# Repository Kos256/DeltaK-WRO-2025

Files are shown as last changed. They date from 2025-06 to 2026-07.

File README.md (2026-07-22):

<center><h1> Delta K - WRO 2025 Future Engineers </h1></center>

<!-- ⚠️⚠️⚠️ REMINDER: ADD TEAM BANNER IMAGE HERE ⚠️⚠️⚠️ -->
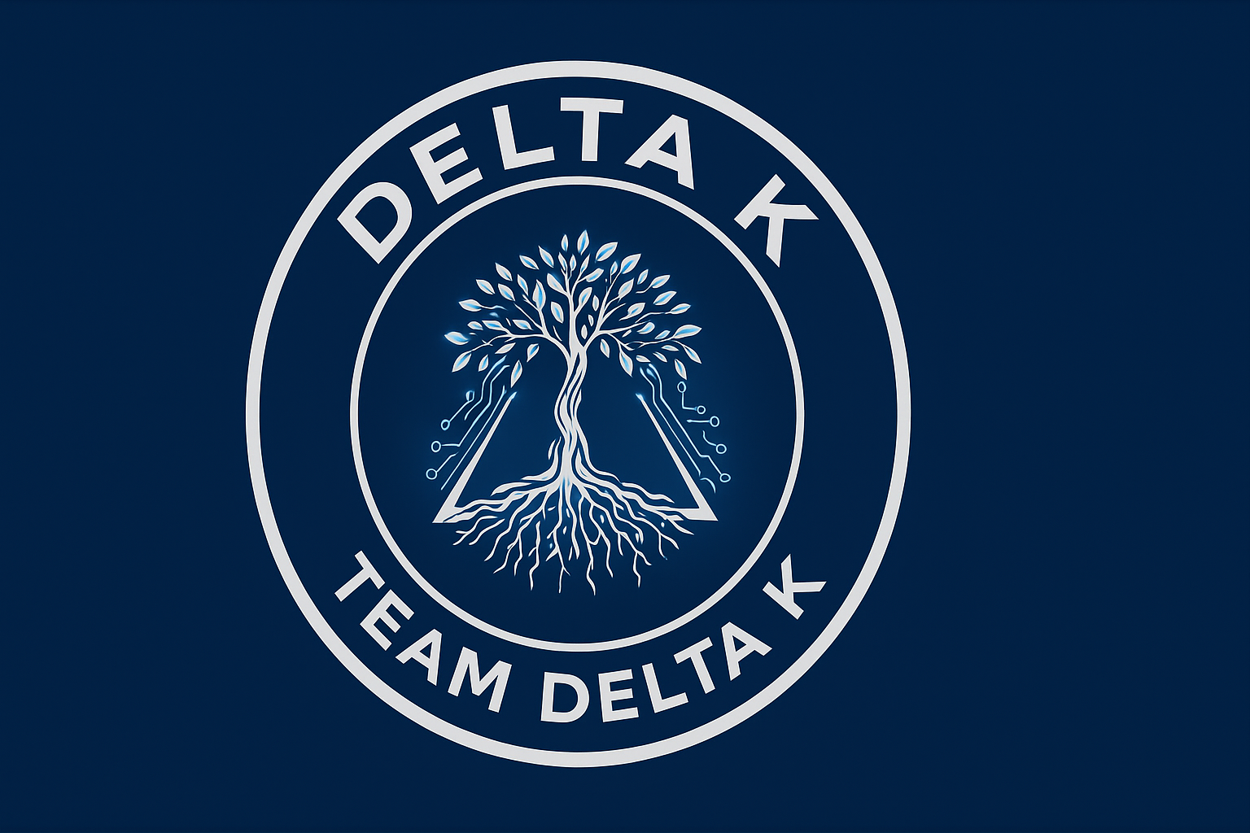
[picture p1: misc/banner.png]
Banner




This repository contains the complete documentation for Team Delta K's autonomous robot for the 2025 World Robot Olympiad Future Engineers competition. Delta Bot was designed, built, and programmed by three dedicated students from Karachi, Pakistan, representing Haque Academy on the international stage.

## Table of Contents
* [The Team](#team)
* [The Challenge](#challenge)
* [The Robot](#robot-image)
* [Performance Video](#video)
* [Development Journey](#development-journey)
* [Mobility Management](#mobility-management)
  * [Custom Motor Design](#custom-motor-design)
  * [Steering System](#steering-system)
  * [Drivetrain](#drivetrain)
  * [Chassis](#chassis)
  * [Wheels](#wheels)
* [Power and Sense Management](#power-and-sense-management)
  * [Raspberry Pi 5](#raspberry-pi-5)
  * [XRP Controller Board](#xrp-board)
  * [Vision System - PiCam2](#picam2)
  * [RPLidar A2M12](#rplidar)
  * [LSM6DSOX IMU](#imu-sensor)
  * [HC-SR04 Ultrasonic Sensor](#ultrasonic)
  * [Motor Encoder](#motor-encoder)
  * [Power System](#power-system)
  * [Circuit Diagram](#circuit-diagram)
* [Software Architecture](#software-architecture)
  * [Code Structure](#code-structure)
  * [Computer Vision](#computer-vision)
  * [Sensor Fusion](#sensor-fusion)
  * [Communication Protocol](#communication)
* [Obstacle Management](#obstacle-management)
  * [Qualification Round Strategy](#quali-strategy)
  * [Obstacle Round Strategy](#obstacle-strategy)
  * [Parking Challenge](#parking-challenge)
* [Code Implementation](#code-implementation)
  * [Main Control Loop](#main-loop)
  * [LiDAR Mapping](#lidar-code)
  * [Color Detection](#color-detection-code)
  * [IMU Integration](#imu-code)
  * [Motor Control](#motor-control-code)
  * [Obstacle Avoidance](#obstacle-avoidance-code)
* [Robot Construction Guide](#robot-construction-guide)
* [Cost Report](#cost-report)
* [Testing & Results](#testing-results)
* [Future Improvements](#future-improvements)
* [Acknowledgments](#acknowledgments)
* [Resources](#resources)
* [License](#license)

---

## The Team 

<!-- ⚠️⚠️⚠️ REMINDER: ADD ALL TEAM MEMBER PHOTOS IN ./team-photos/ FOLDER ⚠️⚠️⚠️ -->

### Kabir - Project Manager & Documentation Lead
<p align="center">
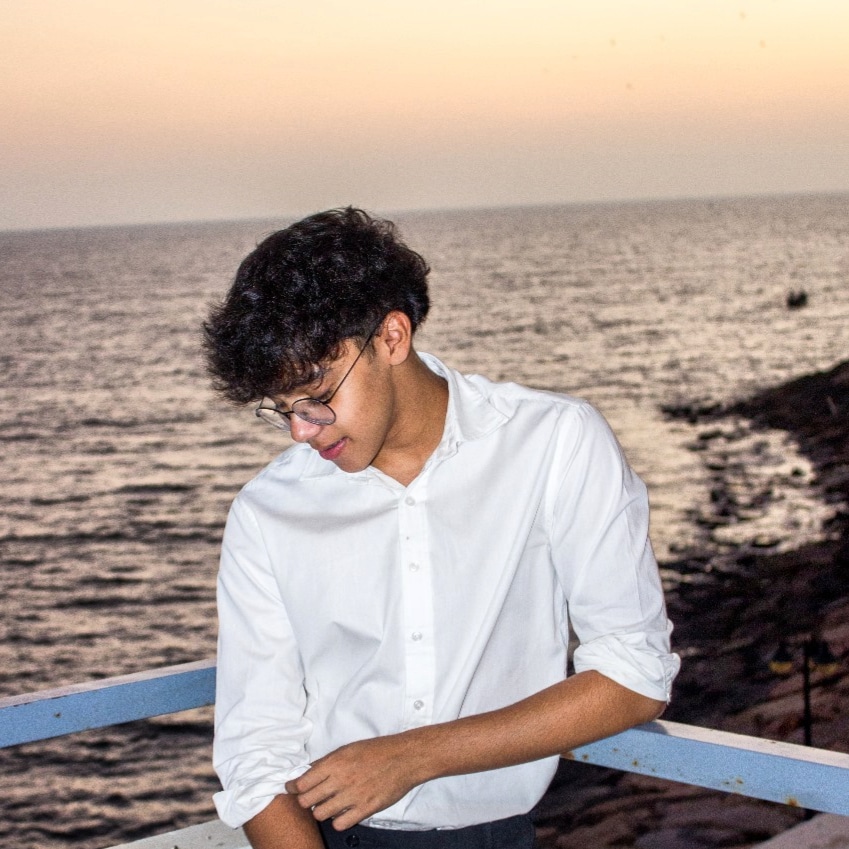
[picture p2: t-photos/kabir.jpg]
Kabir
  
</p>

**Age:** 15

**School:** Haque Academy, Karachi, Pakistan

**Role:** Project Manager & Documentation Lead

**Description:** Hi! I'm Kabir, and I'm passionate about programming, public speaking, leadership, and staying fit through gymming. WRO 2025 represents an incredibly interesting challenge and a golden opportunity to showcase our robotics skills on the international stage. My strengths lie in organizing the team, maintaining comprehensive documentation, managing our GitHub repository, and planning the robot's development roadmap. I previously qualified at the national level for the International Robot Olympiad (IRO) in Greece, which gave me valuable competition experience. What I enjoy most about my role is seeing our robot's progress grow in real-time—watching our ideas transform from sketches to a fully functional autonomous vehicle is incredibly rewarding. Leading this team and documenting every step of our journey has taught me that success comes from meticulous planning, clear communication, and relentless dedication to improvement.

---

### Kosain - Lead Programmer
<p align="center">
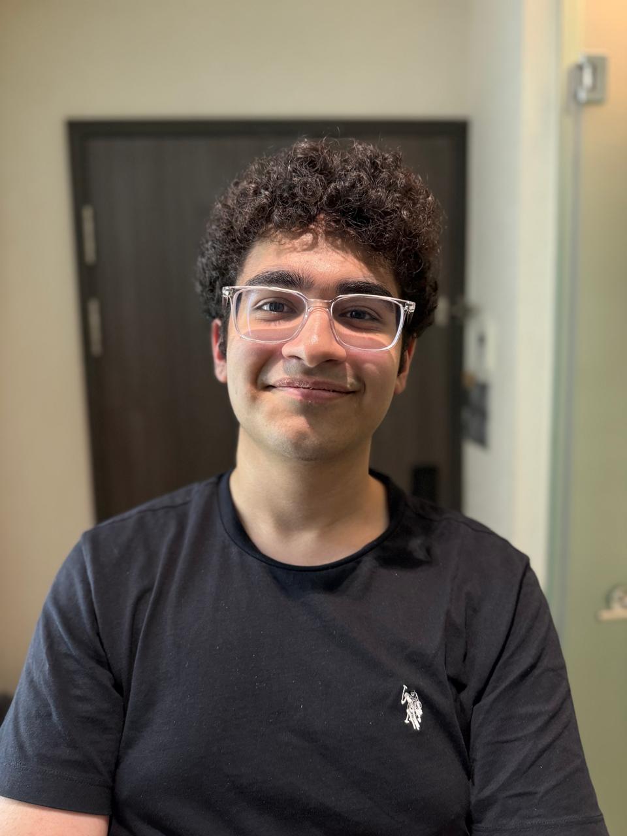
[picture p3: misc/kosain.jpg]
Kosain
  
</p>

**Age:** 16

**School:** Haque Academy, Karachi, Pakistan

**Role:** Lead Programmer

**Description:** Hello! I'm Kosain, the lead programmer for Team Delta K. I've been fascinated by programming since I was 6 or 7 years old—what drew me in was how extremely logical it is, and my school provided many opportunities to learn and grow. Over the years, I've become proficient in Python, C, C++, C#, HTML, CSS, and JavaScript. I've worked on diverse projects including wireless remote control protocols, AI frontend development, image editor software built on ESP32, an electronic dice, a formula calculator, and even a malware debunker tool. What I love most about programming is its pure logic—every problem has a solution if you think systematically. Beyond software, I have a strong interest in the hardware side of things, which is why robotics is the perfect blend of my passions. For this competition, I'm handling all the computer vision, sensor integration, and control algorithms that bring Delta Bot to life. The challenge of making real-time decisions based on multiple sensor inputs is exactly the kind of complex problem I thrive on solving.

---

### Rayyan - Lead Hardware & Construction
<p align="center">
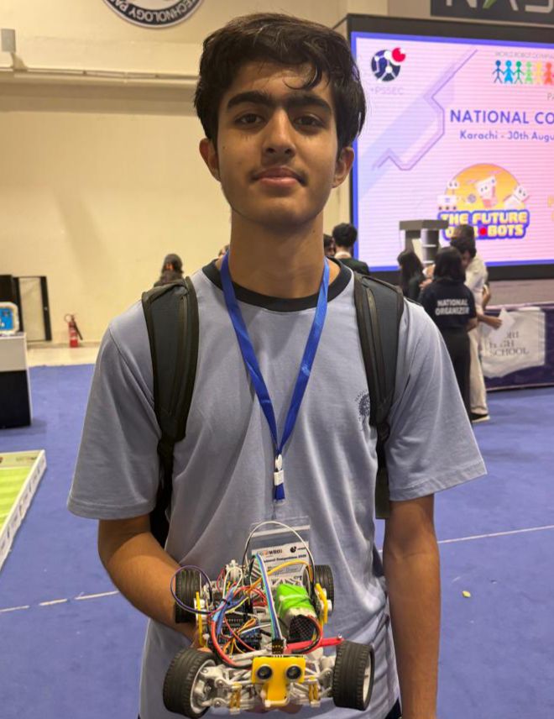
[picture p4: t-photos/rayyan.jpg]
Rayyan
  
</p>

**Age:** 15

**School:** Haque Academy, Karachi, Pakistan

**Role:** Lead Hardware & Construction

**Description:** Hi ! I’m Rayyan, I have been passionate about robotics, engineering, and hands-on building for as long as I can remember. My STEM journey began with the First LEGO League Junior National Competition in 2019, and since then I’ve developed strong skills in 3D printing, CAD design, and mechanical construction. I’m especially fascinated by gears, linkages, and structural integrity, and I love modifying and customizing RC cars into high-speed performance builds.
As the Lead Hardware & Construction member of Team Delta K, I designed, assembled, and 3D-printed our autonomous robot for the WRO Future Engineers category. My interest in fabrication also inspired me to co-found @rk3dprints, where my teammate and I create innovative 3D-printed products.
Outside robotics, I enjoy fishing, building natural habitat aquariums, rowing as Captain of my school’s team, and exploring culinary arts. I’m excited to gain international exposure at WRO 2025 and take my passion for innovation to the global stage.

---

### Ali Saif - Coach
<p align="center">
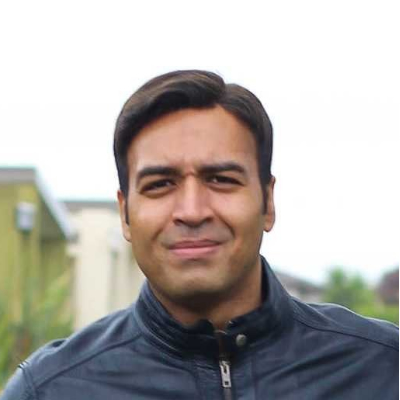
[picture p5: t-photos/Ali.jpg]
Ali Saif
  
</p>

**Role:** Team Coach

**Description:** Leveraging a robust engineering background, Ali Saif is an entrepreneur dedicated to solving challenging market problems through innovation. He combine technical rigor with business acumen to build and grow companies that are disrupting the technology landscape.

---

### Team Photo
<p align="center">
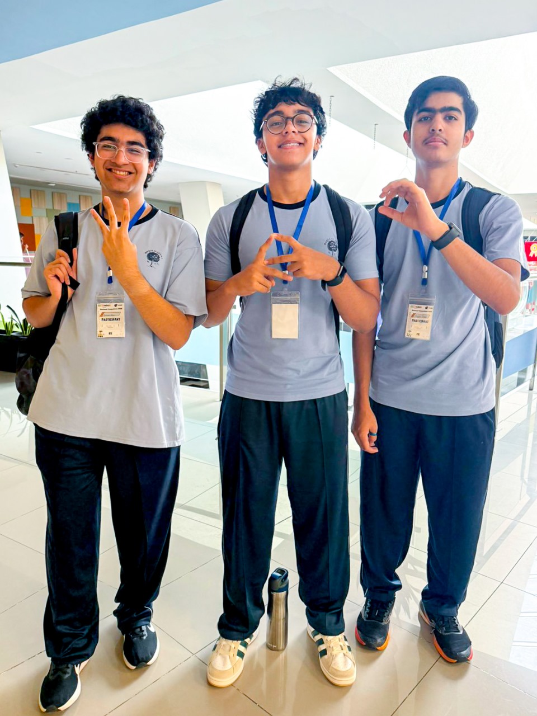
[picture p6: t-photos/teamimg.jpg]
Team Delta K
  
</p>

<!-- ⚠️⚠️⚠️ REMINDER: ADD TEAM FORMATION STORY & DYNAMICS ⚠️⚠️⚠️ -->
<!-- Include: How the team formed, how you knew each other, why you decided to work together, team dynamic, how you divide work, resolve disagreements, memorable moments during development -->

**Team Formation:** [Describe how Delta K was formed, how team members knew each other beforehand, what brought you together for WRO, and what makes your team dynamic special]

**Team Dynamic:** [Explain how you work together, divide responsibilities, handle disagreements, celebrate successes, and any funny or memorable moments during the 6-month development process]

---

## The Challenge 

The **[WRO 2025 Future Engineers - Self-Driving Cars](https://wro-association.org/)** challenge represents the pinnacle of student robotics competitions, inviting teams worldwide to design, build, and program fully autonomous vehicles. The competition simulates real-world self-driving car scenarios with three distinct challenges:

**1. Open Challenge (Qualification Round):** Robots must autonomously navigate a track with randomly placed walls, completing three laps in the fastest time possible. The direction of travel (clockwise or counterclockwise) is determined by detecting colored lines (orange or blue) at the track's corners.

**2. Obstacle Challenge (Final Round):** Building on the qualification round, robots must now avoid randomly placed traffic signs (red and green pillars) while maintaining speed and efficiency. The challenge includes a mandatory U-turn rule: if the last obstacle in the second lap is red, the robot must turn around and complete the final lap in the opposite direction.

**3. Parking Challenge:** After completing the obstacle rounds, robots must identify a parking space marked by magenta walls and execute a precise parallel parking maneuver.

**Key Technical Requirements:**
- **Mobility Management:** Efficient motor control, precise steering, and robust mechanical design
- **Sensor Fusion:** Integration of multiple sensors (camera, LiDAR, IMU, encoders) for environmental awareness
- **Computer Vision:** Real-time color detection and object recognition for obstacles and parking spaces
- **Path Planning:** Dynamic navigation using sensor data to avoid collisions and optimize routes
- **Documentation:** Comprehensive engineering documentation in a public GitHub repository demonstrating the entire development process

**Scoring Criteria:**
- Performance in competition rounds (speed, accuracy, obstacle avoidance)
- Quality and completeness of engineering documentation
- Innovation in design and problem-solving approaches
- Team presentation and ability to explain technical decisions

This challenge emphasizes the complete engineering process—from conceptual design through iterative prototyping, testing, and final implementation. It pushes teams to integrate mechanical engineering, electronics, computer science, and project management skills while fostering creativity, teamwork, and resilience in the face of technical challenges.

Learn more about the WRO 2025 challenge rules and specifications [here](https://wro-association.org/competition/season-2025/).

---

## Photos of Our Robot: Delta Bot 

<!-- ⚠️⚠️⚠️ REMINDER: ADD ALL SIX ROBOT PHOTOS (front, back, left, right, top, bottom) IN ./robot-photos/ FOLDER ⚠️⚠️⚠️ -->

Delta Bot represents our team's sixth month of intensive engineering, combining cutting-edge sensors with custom mechanical solutions. Powered by a Raspberry Pi 5 and equipped with RPLidar for 360-degree environmental mapping, Delta Bot achieves autonomous navigation through advanced sensor fusion and real-time path planning.

| Front View | Back View | 
| :--: | :--: |
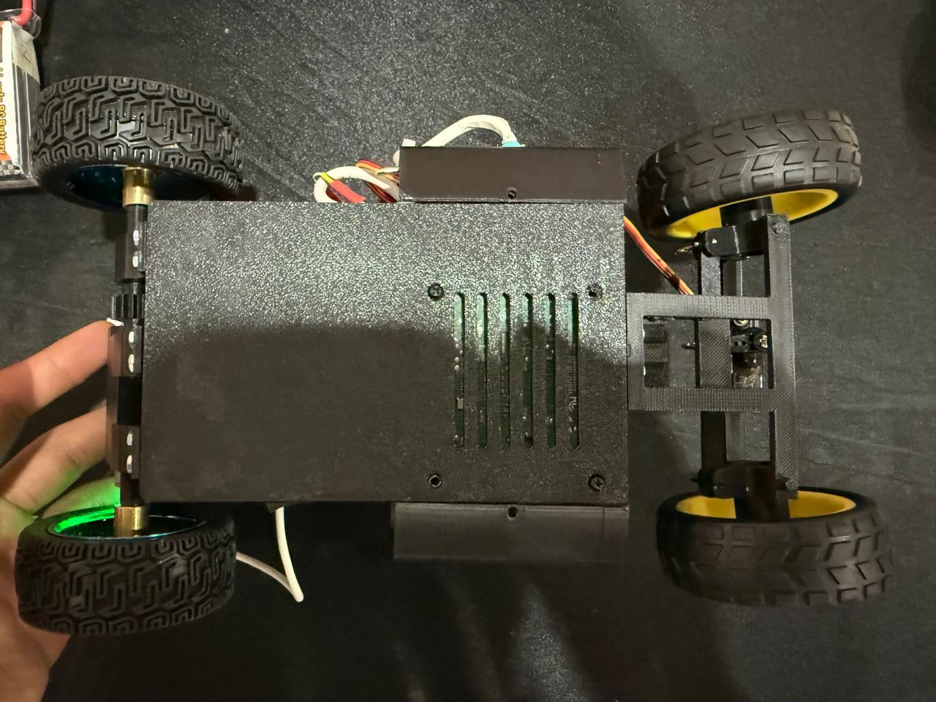
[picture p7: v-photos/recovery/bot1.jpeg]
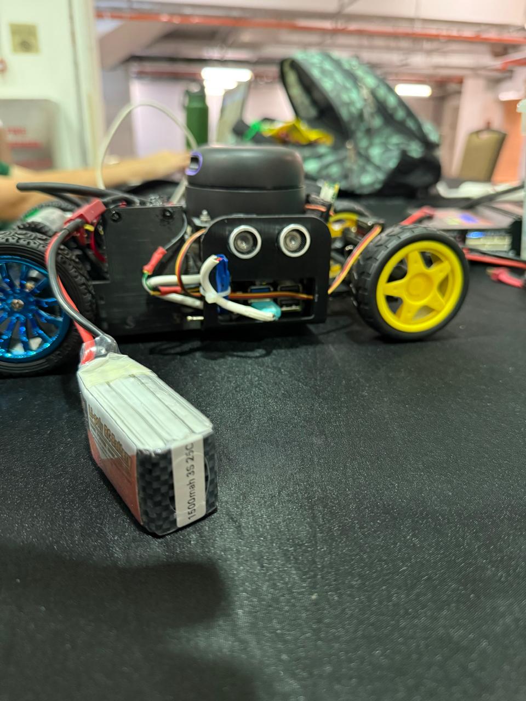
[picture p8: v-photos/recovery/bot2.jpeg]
|  |  |
| **Left View** | **Right View** |
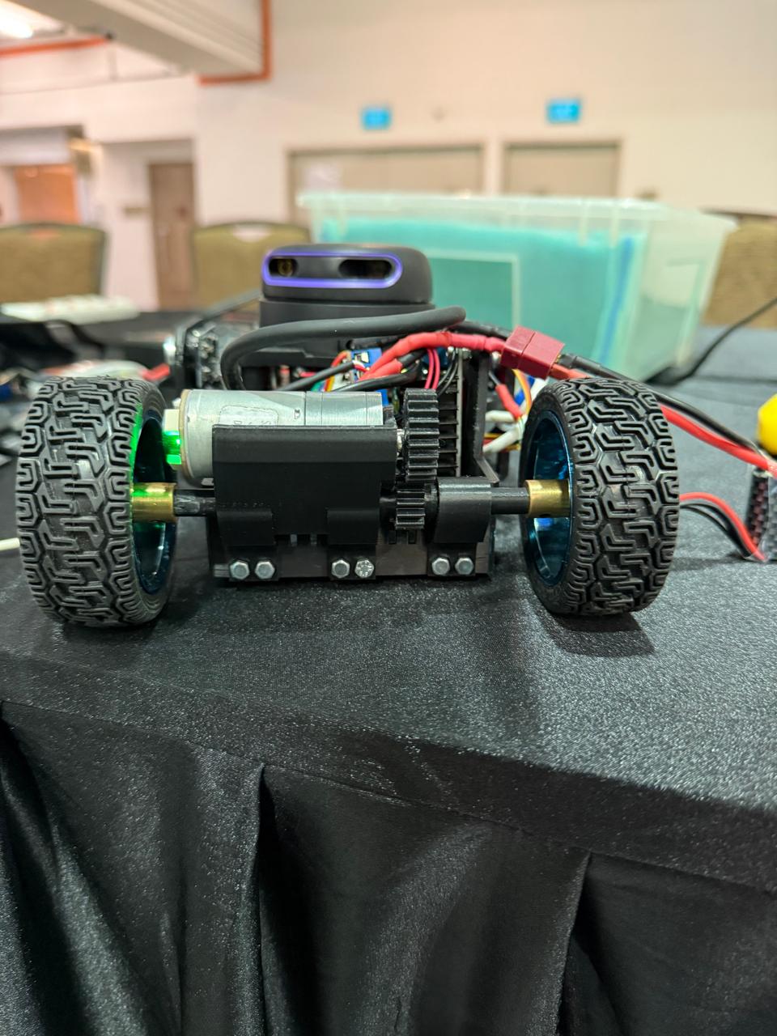
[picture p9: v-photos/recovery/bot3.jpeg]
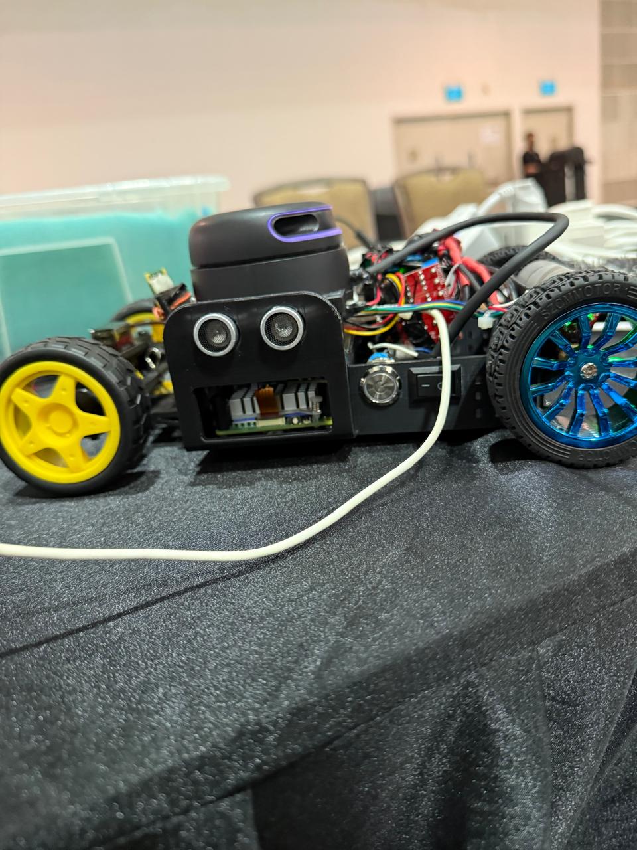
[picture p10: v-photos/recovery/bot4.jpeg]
|  |  |
| **Top View** | **Bottom View** |
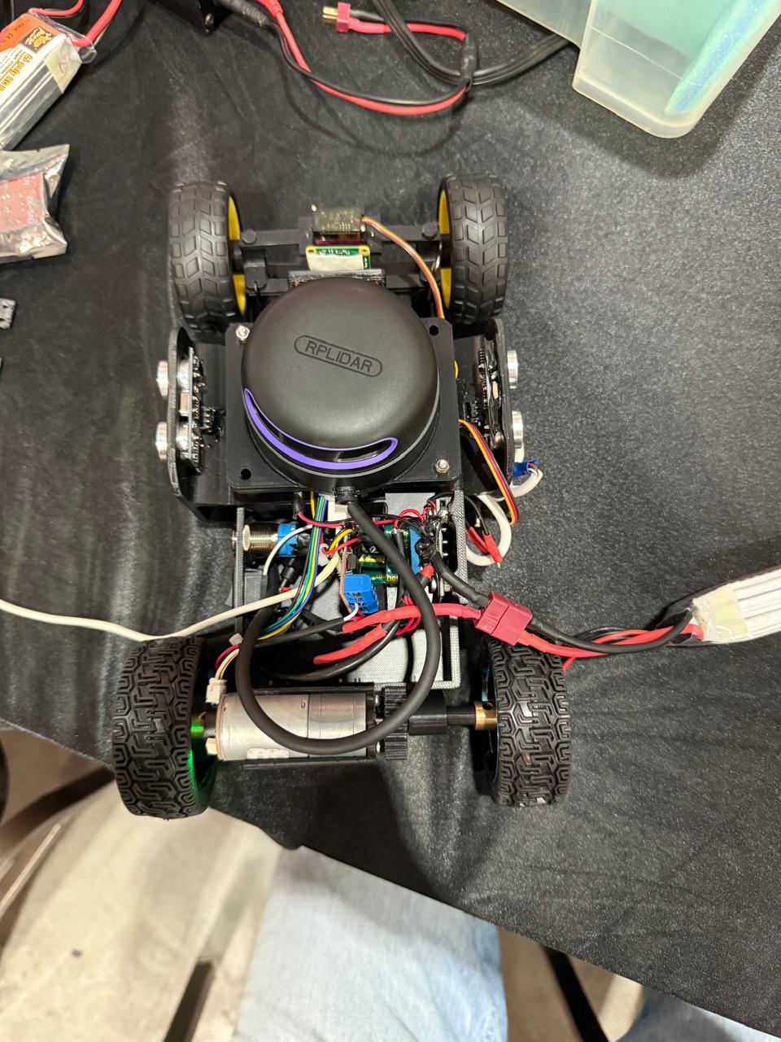
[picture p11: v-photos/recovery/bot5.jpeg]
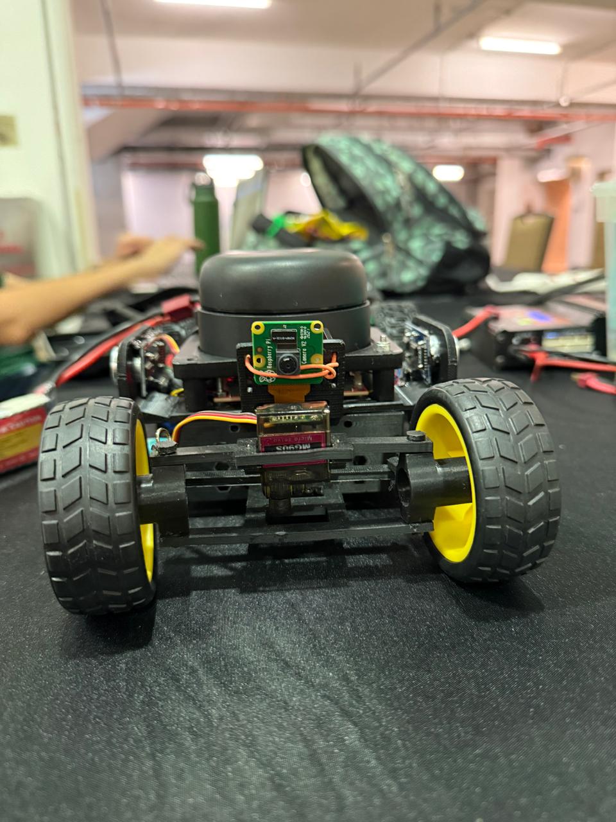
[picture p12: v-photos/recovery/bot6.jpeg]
|  |  |

**Key Specifications:**
- **Dimensions:** 270mm x 190mm x 100mm
- **Weight:** 1030g
- **Brain:** Raspberry Pi 5 (8-core CPU, 8GB RAM)
- **Vision:** PiCam2 with OpenCV processing
- **Mapping:** RPLidar A2M12 (360° scanning, 12m range)
- **Navigation:** LSM6DSOX IMU (6-axis gyroscope + accelerometer)
- **Drive System:** Custom dual-axle motor with DG01D-E encoder
- **Steering:** SG90 micro servo with parallel linkage mechanism
- **Power:** 3x 1500mAh LiPo batteries with voltage regulation
- **Construction:** 3D printed PLA+ & ABS components

---
<!-- uncomment this when performance video is uploaded
## Our Performance Video 

Watch Delta Bot in action [here](https://https://google.com)
**(link to youtube video has yet to be added)**

**Competition Performance Highlights:**
- **Qualification Round Best Time:** 14 seconds
- **Obstacle Round Score:** 10.0 (14 points)
- **National Competition Result:** 3rd Place (Qualified for International Competition)
-->
---
## Development Journey 

Delta Bot's development spanned six months and four major design iterations, each addressing critical challenges and pushing our capabilities further.

### **Iteration 1: The Arduino Attempt (Month 1)**
Our first design used an Arduino Uno as the main controller with basic ultrasonic sensors for navigation. We quickly discovered the Arduino's limitations:
- **Camera compatibility** was extremely unstable and unreliable
- **Color sensors** proved inadequate for the obstacle challenge—they couldn't reliably distinguish between red and green traffic signs
- **Processing power** was insufficient for real-time decision-making

**Lesson Learned:** Budget hardware severely limits autonomous capabilities. Vision and processing power are non-negotiable for competition-level performance.

### **Iteration 2: Raspberry Pi 4 with Ambition (Months 2-3)**
We upgraded to a Raspberry Pi 4, expecting significant improvements. Instead, we encountered our biggest setback:
- **Camera communication** took nearly a month to debug—the Pi 4 struggled with consistent PiCam integration
- **LiDAR data overload**—the RPLidar A2M12 generates massive amounts of data, completely overwhelming the Pi 4's processing capabilities
- The robot would freeze or make delayed decisions, making it completely uncompetitive

**Breakthrough Moment:** We realized we needed significantly more processing power, not just incremental upgrades.

### **Iteration 3: The Raspberry Pi 5 Revolution (Month 4)**
Switching to the Raspberry Pi 5 transformed our project:
- **8-core processor** effortlessly handled LiDAR data, camera processing, and navigation algorithms simultaneously
- **Improved camera support** eliminated communication issues entirely
- **Real-time performance** finally achieved—Delta Bot could process sensor data and react within milliseconds

This upgrade was expensive but absolutely critical to our success.

### **Iteration 4: Mechanical Refinement & Custom Motor (Months 5-6)**
With electronics stable, we focused on mechanical optimization:
- **30+ 3D printed parts:** Designed and refined chassis, motor mounts, sensor holders, and linkages
- **Weight optimization:** Iterative printing reduced unnecessary material while maintaining structural integrity
- **Parallel linkage steering:** Achieved reliable, precise steering without complex Ackermann geometry

### **Crisis at Nationals**
Just before the obstacle round at WRO Pakistan Nationals, disaster struck: ultrasonic sensor wiring short-circuited, melting the wires. With only minutes before our run, the team had to:
1. Quickly strip and reconnect all ultrasonic sensor wiring
2. Test functionality without time for proper debugging
3. Compete with hastily repaired electronics

Despite this setback, Delta Bot placed **3rd nationally** and qualified for the **international competition**—a testament to the robot's robust design and the team's ability to perform under extreme pressure.

### **Key Takeaways:**
- **Start with sufficient processing power**—upgrading mid-project wastes time
- **Plan for redundancy**—backup sensors and modular wiring saved us at nationals
- **Document everything**—clear documentation allowed rapid troubleshooting
- **Iterate relentlessly**—each failure taught us what really matters in autonomous robotics

---

# Mobility Management 

Delta Bot's mobility system is the result of extensive iteration and custom engineering. After testing multiple motor configurations and steering mechanisms, we developed a unique dual-axle drivetrain that maximizes encoder precision while maintaining a compact footprint.

## Custom Motor Design 

<!-- Include: Disassembled motor photos, encoder integration photos, dual-axle configuration photos -->
<p align="center">
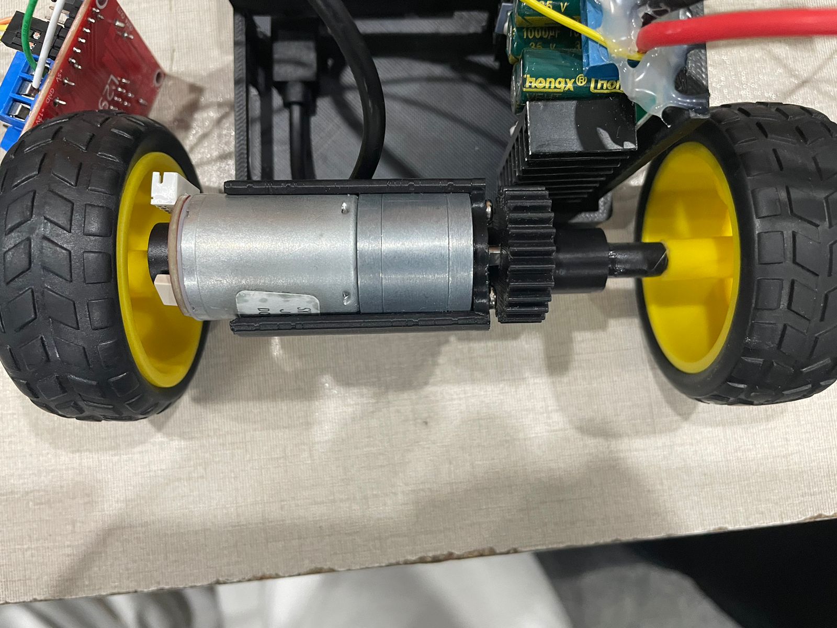
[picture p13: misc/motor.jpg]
Custom Motor Assembly
  
</p>

### Design Philosophy

Off-the-shelf motors with encoders couldn't meet our specific requirement: the motor needed to physically sit **between** the two rear wheels, with the axle passing through both sides. This configuration was essential for:
- **Balanced weight distribution** across the rear axle
- **Direct mechanical connection** to both wheels without complex differential systems
- **Precise encoder feedback** for accurate distance measurement
- **Compact chassis design** by centralizing the motor

### Custom Modifications

Starting with a **TT Motor Yellow Geared DC Motor body**, we performed the following modifications:

1. **Motor Disassembly:** Carefully disassembled the motor casing to access the internal shaft
2. **Encoder Integration:** Integrated the **DG01D-E Motor Encoder** directly onto the motor shaft for absolute position tracking
3. **Dual-Axle Slots:** Machined slots on both sides of the motor housing to allow the axle to pass completely through
4. **Reassembly with Precision:** Reassembled the motor with the encoder securely mounted, ensuring no mechanical play

**Technical Specifications:**
- **Base Motor:** TT Motor Yellow Geared DC Motor
- **Encoder:** DG01D-E (quadrature encoder for precise position feedback)
- **Gear Ratio:** [Add gear ratio]
- **Operating Voltage:** 6-12V
- **Configuration:** Dual-axle pass-through design
- **Mounting:** Custom 3D printed motor mounts

### Why This Matters

The custom motor design eliminates the need for a differential while providing:
- **Encoder precision:** Real-time wheel position feedback accurate to fractions of a degree
- **Direct drive efficiency:** No power loss through gears or belts
- **Simplified control:** Both rear wheels are mechanically locked together, simplifying motor control algorithms
- **Compact footprint:** The motor doesn't protrude from the chassis, reducing overall robot size

---

## Steering System 
<p align="center">
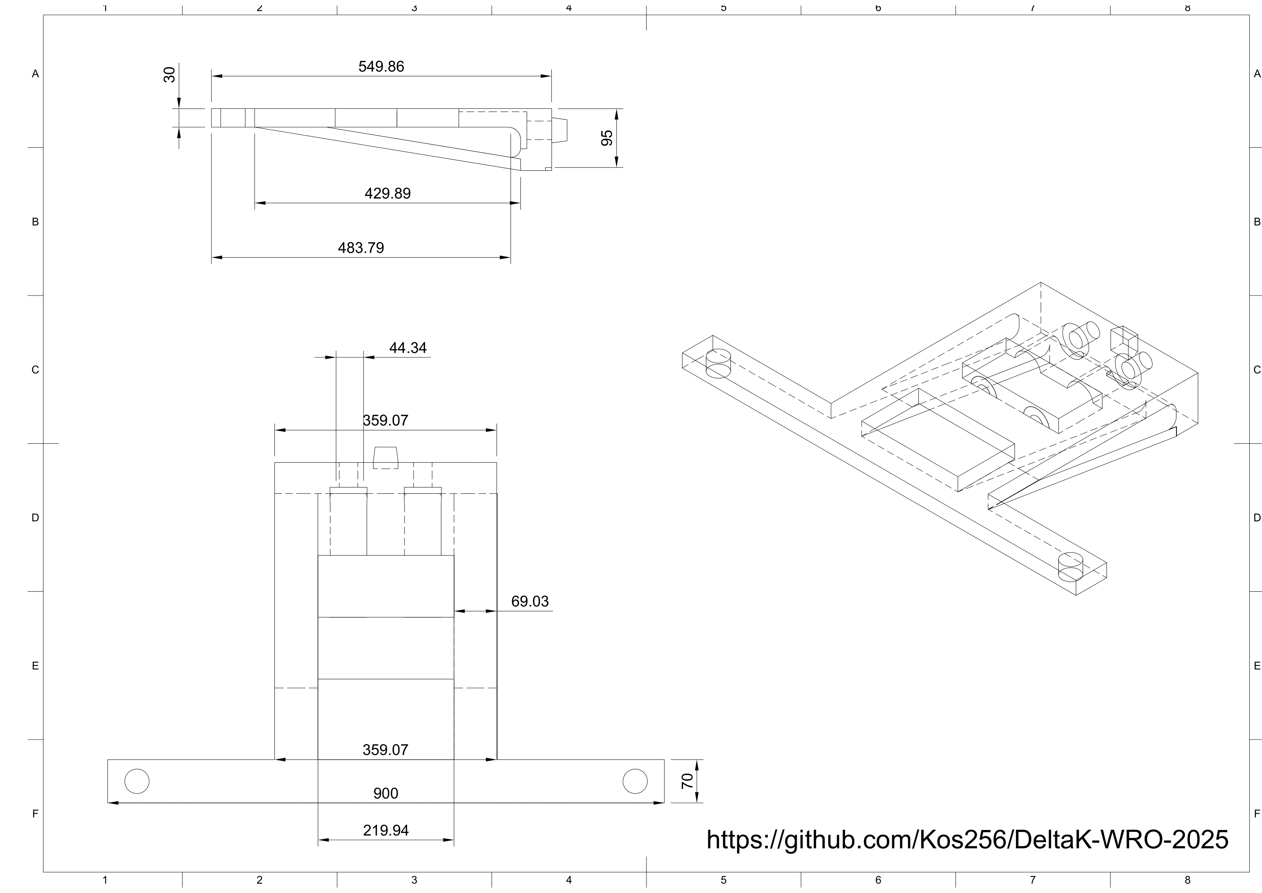
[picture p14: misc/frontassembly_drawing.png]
Steering System
  
</p>

### Parallel Linkage Design

After experimenting with Ackermann steering and direct servo-to-wheel connections, we settled on a **parallel linkage mechanism** for its simplicity, reliability, and sufficient turning radius.
<p align="center">
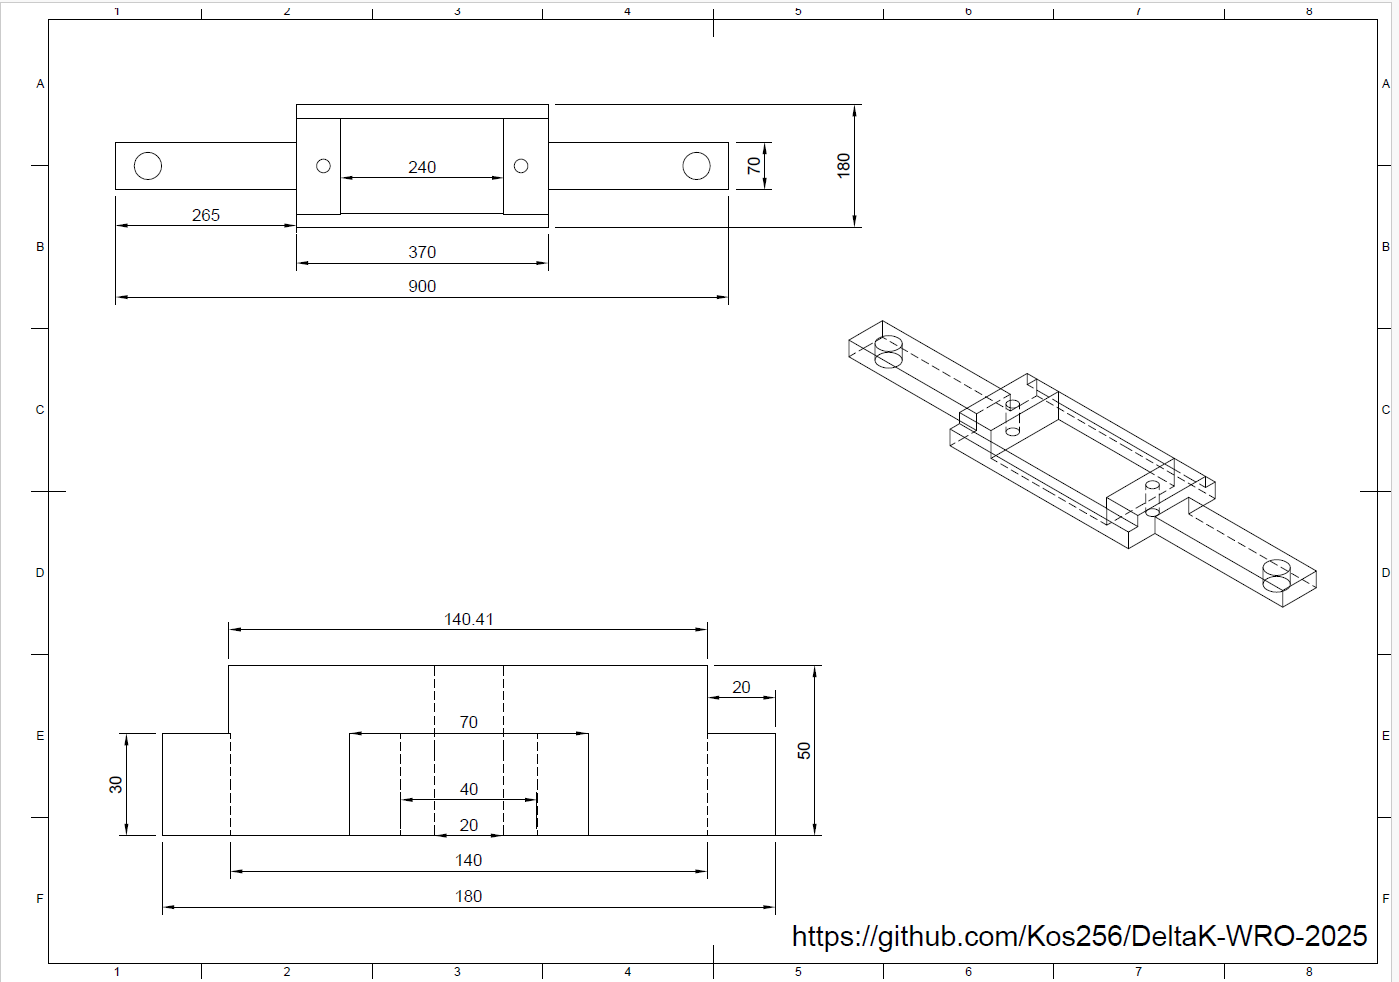
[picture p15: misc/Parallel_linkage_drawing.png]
Parallel Linkage View
   
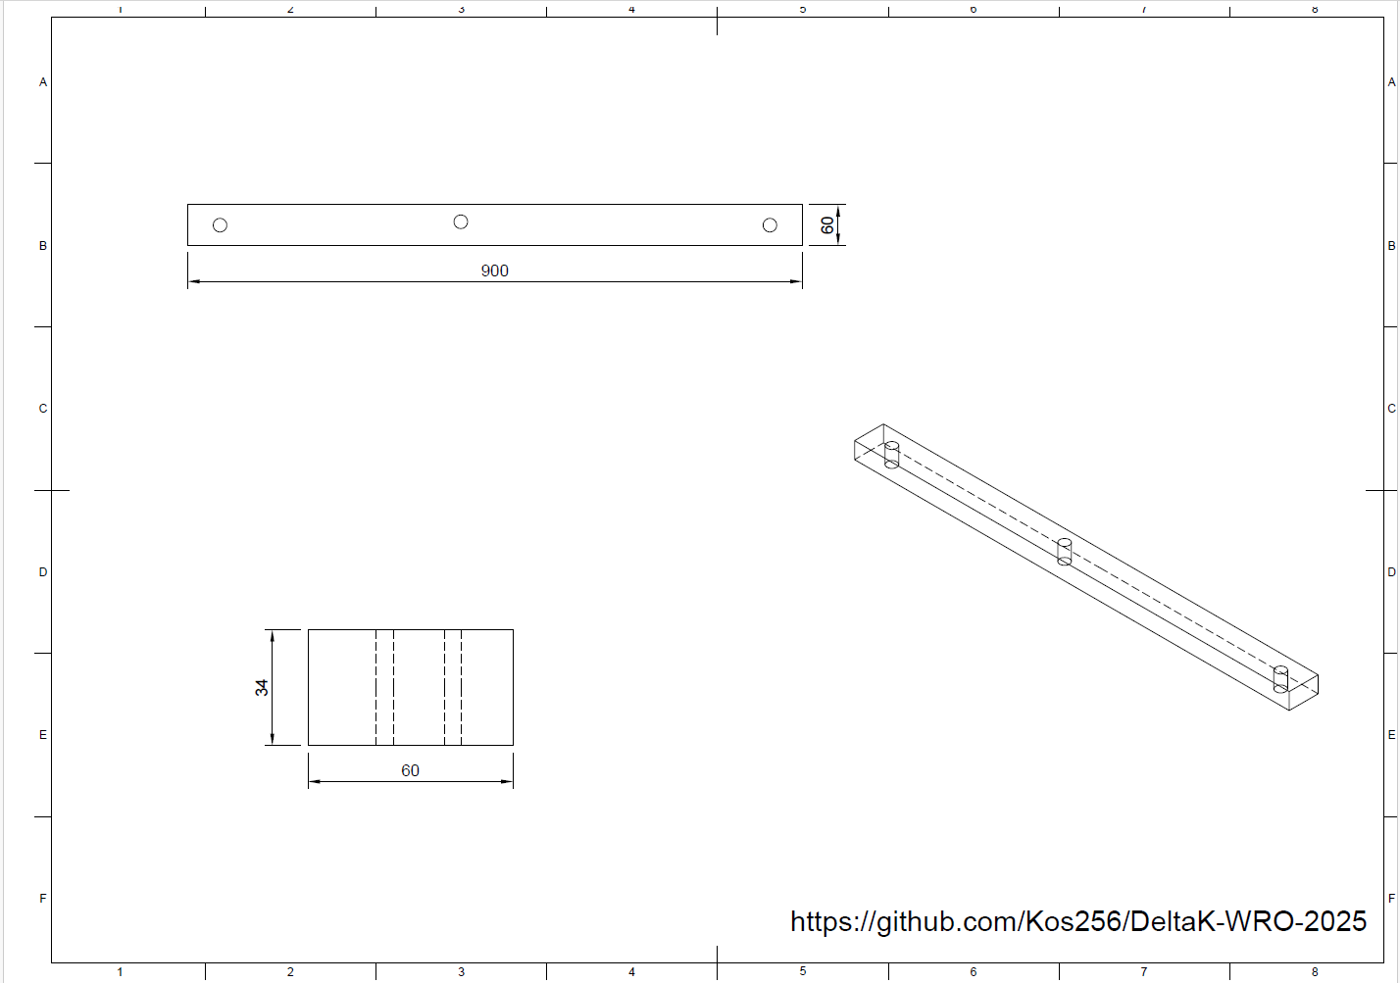
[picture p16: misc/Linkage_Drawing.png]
Linkage View
   
</p>
**Key Components:**
- **SG90 9g Micro Servo Motor**
  - Torque: 1.8 kg·cm (4.8V)
  - Speed: 0.1 sec/60° (4.8V)
  - Rotation: 180° (sufficient for full left/right steering)
  - Weight: 9g (minimal impact on front-end weight distribution)

- **3D Printed Linkages:** Connect the servo horn to both front wheel holders, ensuring synchronized steering
- **Wheel Holders:** Custom-designed to allow smooth rotation while maintaining structural rigidity

### Steering Geometry

The parallel linkage geometry provides:
- **Turning Radius:** Approximately [X] cm (suitable for WRO track dimensions)
- **Steering Angle:** ±[X]° from center
- **Response Time:** <100ms from command to full deflection

While not true Ackermann steering (which would provide optimal tire scrub reduction), our testing showed that for Delta Bot's weight and speed, the parallel linkage performs adequately without significant tire wear or turning inefficiency.

<!-- ⚠️⚠️⚠️ REMINDER: ADD 3D BLUEPRINTS OF STEERING LINKAGES AND WHEEL HOLDERS ⚠️⚠️⚠️ -->

**Potential Improvements:**
- Implement Ackermann geometry for competition at higher speeds
- Use ball-bearing joints instead of printed pivots to reduce friction
- Upgrade to a digital servo for finer angle control

---

## Drivetrain 

<!-- ⚠️⚠️⚠️ REMINDER: ADD DRIVETRAIN ASSEMBLY PHOTOS ⚠️⚠️⚠️ -->

### Rear Axle Configuration

The rear axle is the mechanical heart of Delta Bot, directly connecting both rear wheels through the custom motor assembly.

**Axle Design:**
- **Material:** 3D Printed in PLA
- **Diameter:** [Specify diameter in mm]
- **Length:** Spans the full width of the chassis, passing through the motor housing
- **Bearings:** 3D printed bearing holders on each side maintain axle alignment

**Power Transmission:**
1. Motor shaft directly drives the central axle
2. Axle rotates both rear wheels simultaneously (locked differential effect)
3. Encoder tracks axle rotation for precise odometry

### Motor Control

The custom motor is controlled via the **XRP Controller Board**, which features:
- H-bridge motor driver for bidirectional control
- PWM speed control (0-100% duty cycle)
- Current sensing for stall detection
- Integration with Raspberry Pi 5 via serial communication

<!-- ⚠️⚠️⚠️ REMINDER: ADD 3D BLUEPRINTS OF AXLE HOLDERS AND BEARING MOUNTS ⚠️⚠️⚠️ -->

---

## Chassis 

<!-- ⚠️⚠️⚠️ REMINDER: ADD CHASSIS PHOTOS (top view, bottom view, exploded view if available) ⚠️⚠️⚠️ -->
<p align="center">
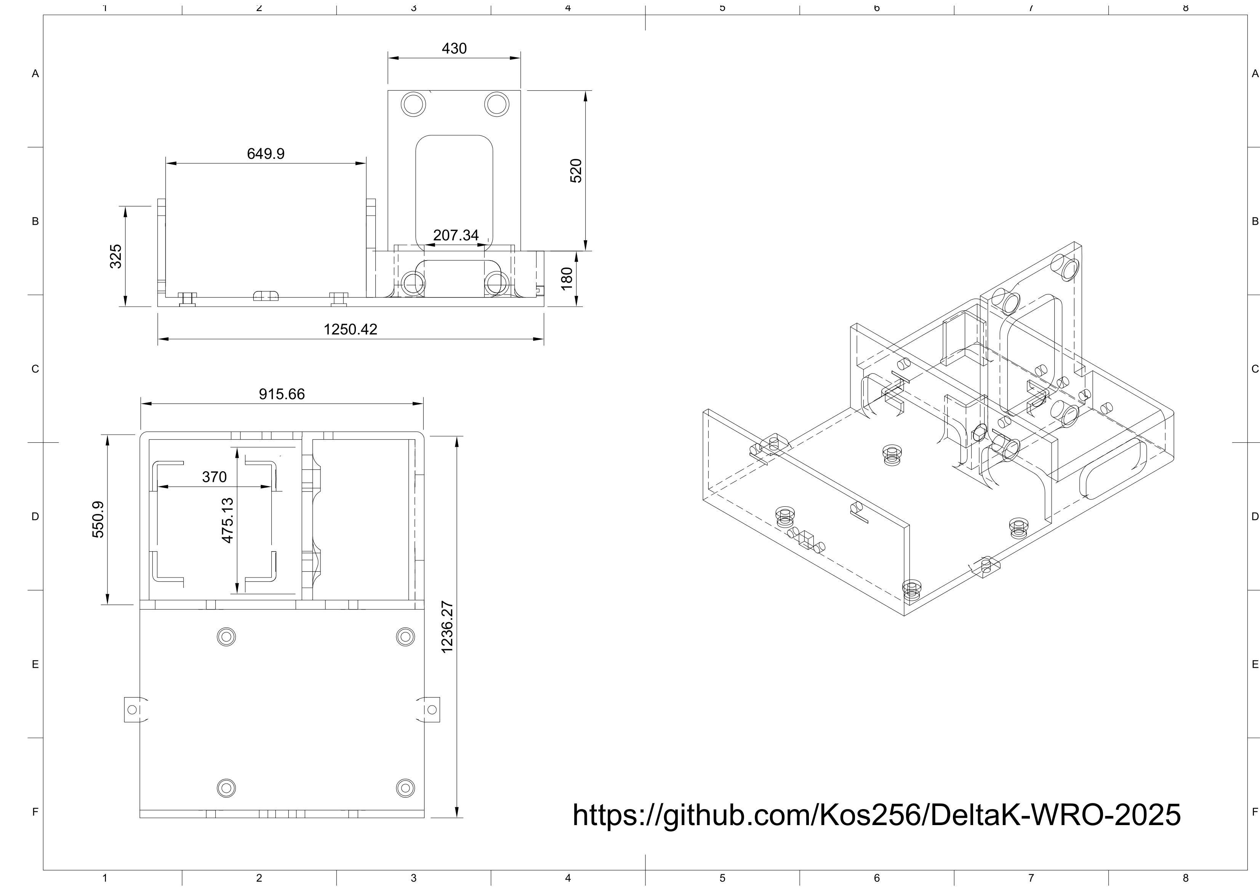
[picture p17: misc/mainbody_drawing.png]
Chassis View
  
</p>

### Design Evolution

Delta Bot's chassis underwent four major iterations before reaching its final form. Our design priorities were:
1. **Lightweight construction** to maximize speed and battery life
2. **Sensor accessibility** for easy debugging and adjustment
3. **Modular design** allowing component swaps without full disassembly
4. **Structural rigidity** to prevent flex during high-speed turns

### 3D Printed Architecture

The chassis consists of **30+ custom 3D printed PLA+ components**, including:

**Main Structural Components:**
- Base chassis plate (main structural member)
- Motor mounting brackets (secure custom motor)
- Front axle holders (support steering mechanism)
- Rear axle bearing holders (maintain alignment)

**Sensor Mounting:**
- RPLidar mounting tower (elevated for 360° visibility)
- PiCam2 mount (angled for optimal field of view)
- Ultrasonic sensor brackets (front-facing backup sensor)
- IMU mounting plate (vibration-isolated for accurate readings)

**Electronics Housing:**
- Raspberry Pi 5 mounting tray
- XRP board mounting brackets
- Battery compartment (secures three LiPo batteries)
- Voltage regulator housing

**Cable Management:**
- Wire routing channels integrated into chassis
- Snap-fit cable clips
- Modular connector access ports

### 3D Printing Specifications

- **Printer:** Creality K1C
- **Material:** PLA+ filament (higher strength than standard PLA)
- **Filament Dryer:** Creality Filament Dryer (prevents moisture absorption for consistent prints)
- **Layer Height:** 0.2mm (balance between strength and print time)
- **Infill:** 20% (sufficient strength without excessive weight)
- **Print Time:** Approximately [X] hours total for all components

<!-- ⚠️⚠️⚠️ REMINDER: ADD ALL 3D MODEL BLUEPRINTS/STL FILES IN ./3d-models/ FOLDER ⚠️⚠️⚠️ -->
<!-- Include: Chassis base, motor mounts, sensor mounts, axle holders, electronics trays, cable management clips -->

**Design Files:**
All 3D models are available in the `./3d-models/` directory in STL format, ready for printing.

---

## Wheels 

<!-- ⚠️⚠️⚠️ REMINDER: ADD WHEEL PHOTOS AND TREAD PATTERN CLOSE-UPS ⚠️⚠️⚠️ -->
<p align="center">
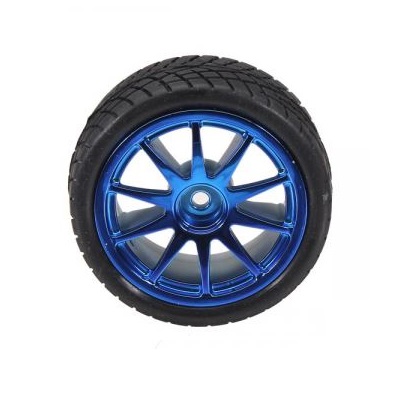
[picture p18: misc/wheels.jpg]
Delta Bot Wheels
  
</p>

**Specifications:**
- **Type:** 65mm Circular Tracked Treaded Wheels
- **Diameter:** 65mm
- **Tread Pattern:** Deep treads for maximum grip on competition mat
- **Material:** Rubber compound
- **Configuration:** 4-wheel drive (2 powered rear wheels, 2 steered front wheels)

**Performance Characteristics:**
- **Grip:** Excellent traction on the foam mat surface used in WRO competitions
- **Rolling Resistance:** Low enough for efficient battery use
- **Durability:** Treaded design resists wear during testing and competition

The 65mm diameter was chosen to balance:
- **Speed:** Larger diameter = higher top speed at same RPM
- **Torque:** Not so large that motor torque becomes insufficient for acceleration
- **Ground Clearance:** Adequate clearance to avoid scraping on uneven mat sections

---

# Power and Sense Management 

Delta Bot's sensor suite represents a comprehensive approach to environmental awareness, combining vision, mapping, inertial measurement, and proximity sensing for robust autonomous navigation.

## Raspberry Pi 5 

<!-- ⚠️⚠️⚠️ REMINDER: ADD RASPBERRY PI 5 INSTALLATION PHOTO ⚠️⚠️⚠️ -->
<p align="center">
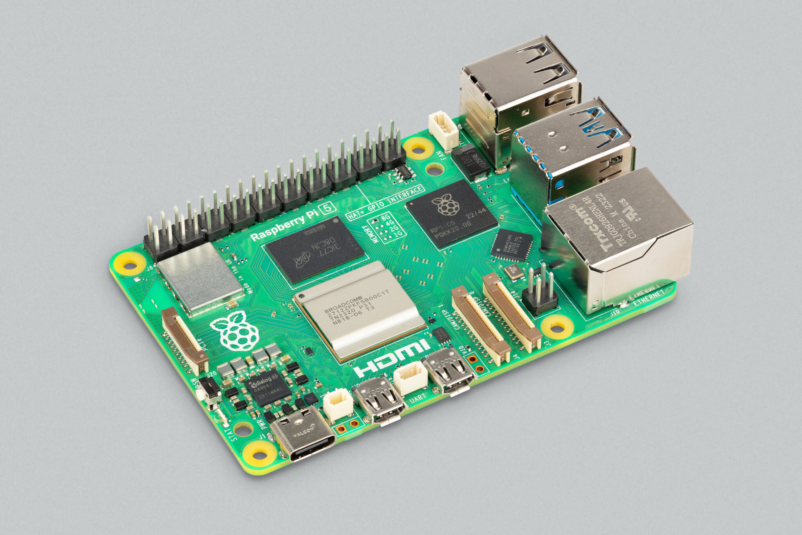
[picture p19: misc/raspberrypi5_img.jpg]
Raspberry Pi 5
  
</p>

### Raspberry Pi 5 Pinout 

<p align="center">
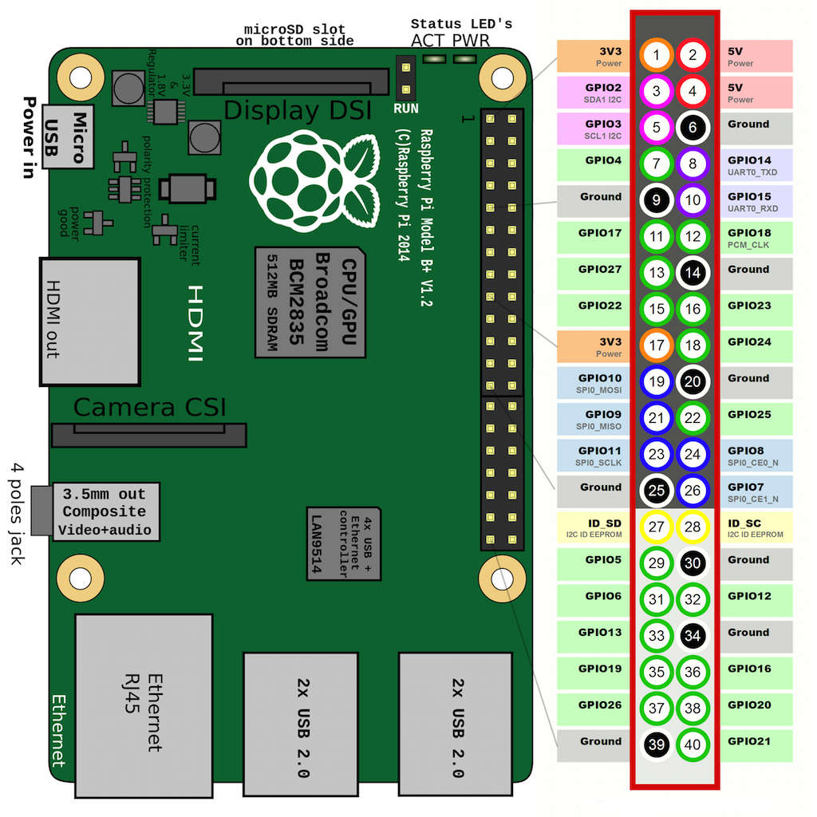
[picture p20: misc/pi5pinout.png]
Raspberry Pi 5 Pin Out
  
</p>

The **Raspberry Pi 5** serves as Delta Bot's main brain, handling all high-level processing tasks.

**Technical Specifications:**
- **Processor:** Broadcom BCM2712 (Quad-core Cortex-A76 @ 2.4GHz)
- **RAM:** 8GB LPDDR4X
- **Storage:** 256GB NVMe SSD (via PCIe interface) - Cost: 46 CAD
- **GPIO:** 40-pin header for sensor and actuator connections
- **USB:** USB 3.0 ports for camera and LiDAR connectivity
- **Power:** 5V/5A via USB-C (delivered through voltage regulation system)

**Why Raspberry Pi 5?**

After struggling with Arduino Uno (insufficient processing power and poor camera support) and Raspberry Pi 4 (overwhelmed by LiDAR data), the Pi 5 was essential:

1. **Massive Processing Power:** The 2.4GHz quad-core processor handles:
   - Real-time LiDAR data processing (thousands of distance measurements per second)
   - Computer vision algorithms (OpenCV) for color detection and object recognition
   - Sensor fusion algorithms combining IMU, encoder, ultrasonic, and vision data
   - Path planning and navigation decision-making
   
2. **Camera Support:** Native support for PiCam2 with no communication issues

3. **Multi-threading:** Runs separate processes for sensor data acquisition, vision processing, and motor control without lag

4. **NVMe Storage:** Fast SSD storage allows quick boot times and efficient data logging

**Cost:** 140 CAD

---

## XRP Controller Board 

<!-- ⚠️⚠️⚠️ REMINDER: ADD XRP BOARD PHOTO AND CONNECTION DIAGRAM ⚠️⚠️⚠️ -->
<p align="center">
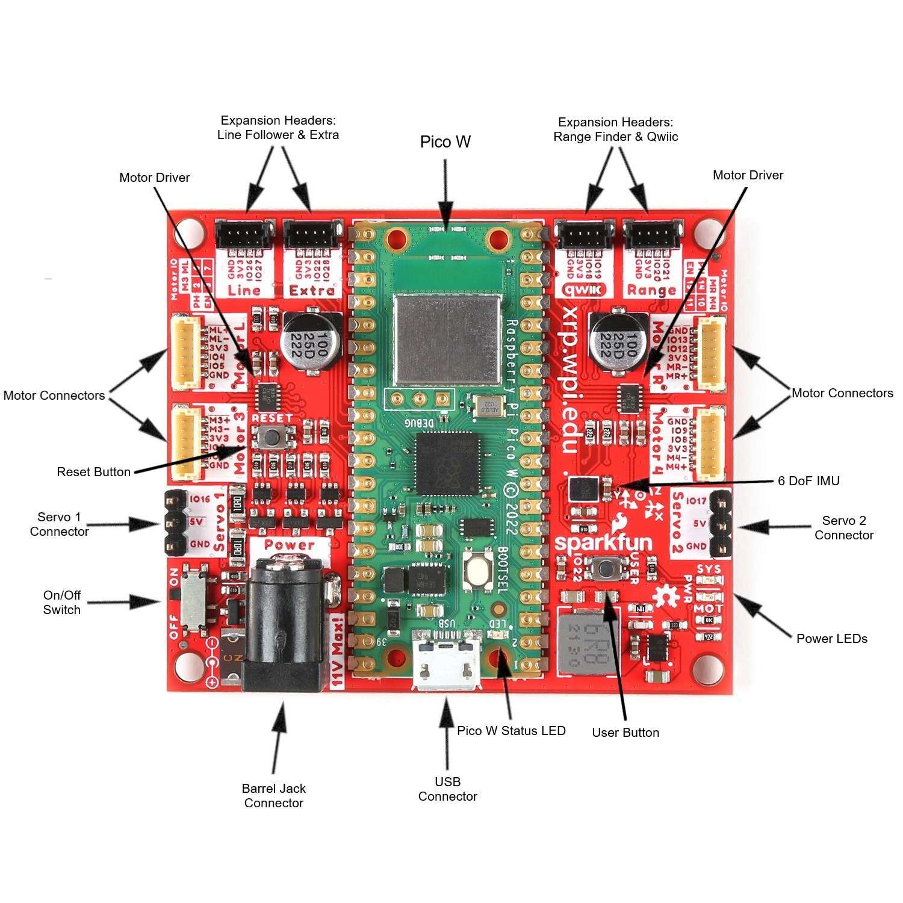
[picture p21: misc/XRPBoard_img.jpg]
XRP Controller Board
  
</p>

The **XRP (Experiential Robotics Platform) Controller Board** serves as the motor control and sensor interface subsystem.

**Key Features:**
- **Built-in Raspberry Pi Pico (RP2040):** Dedicated microcontroller for real-time motor control
- **Integrated LSM6DSOX IMU:** 6-axis gyroscope and accelerometer (included with board)
- **H-Bridge Motor Drivers:** Direct motor control without external drivers
- **Servo Control Pins:** Native support for servo motors
- **Encoder Inputs:** Dedicated pins for quadrature encoder reading
- **GPIO Expansion:** Additional pins for ultrasonic and other sensors

**Communication with Raspberry Pi 5:**
The XRP board communicates with the Raspberry Pi 5 via **serial UART** connection, allowing:
- High-level navigation commands from Pi 5
- Low-level motor control execution on XRP
- Real-time IMU data streaming to Pi 5
- Encoder position feedback for odometry

**Cost:** 60 CAD (includes LSM6DSOX IMU)

---

## Vision System - PiCam2 

<!-- ⚠️⚠️⚠️ REMINDER: ADD CAMERA MOUNTING PHOTO AND FIELD OF VIEW DIAGRAM ⚠️⚠️⚠️ -->
<p align="center">
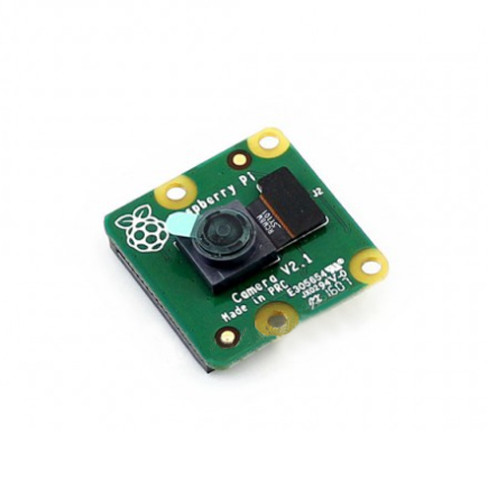
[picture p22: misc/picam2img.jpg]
PiCam2 Mounted on Delta Bot
     
</p>

### Camera Mount Drawing

<p align="center">
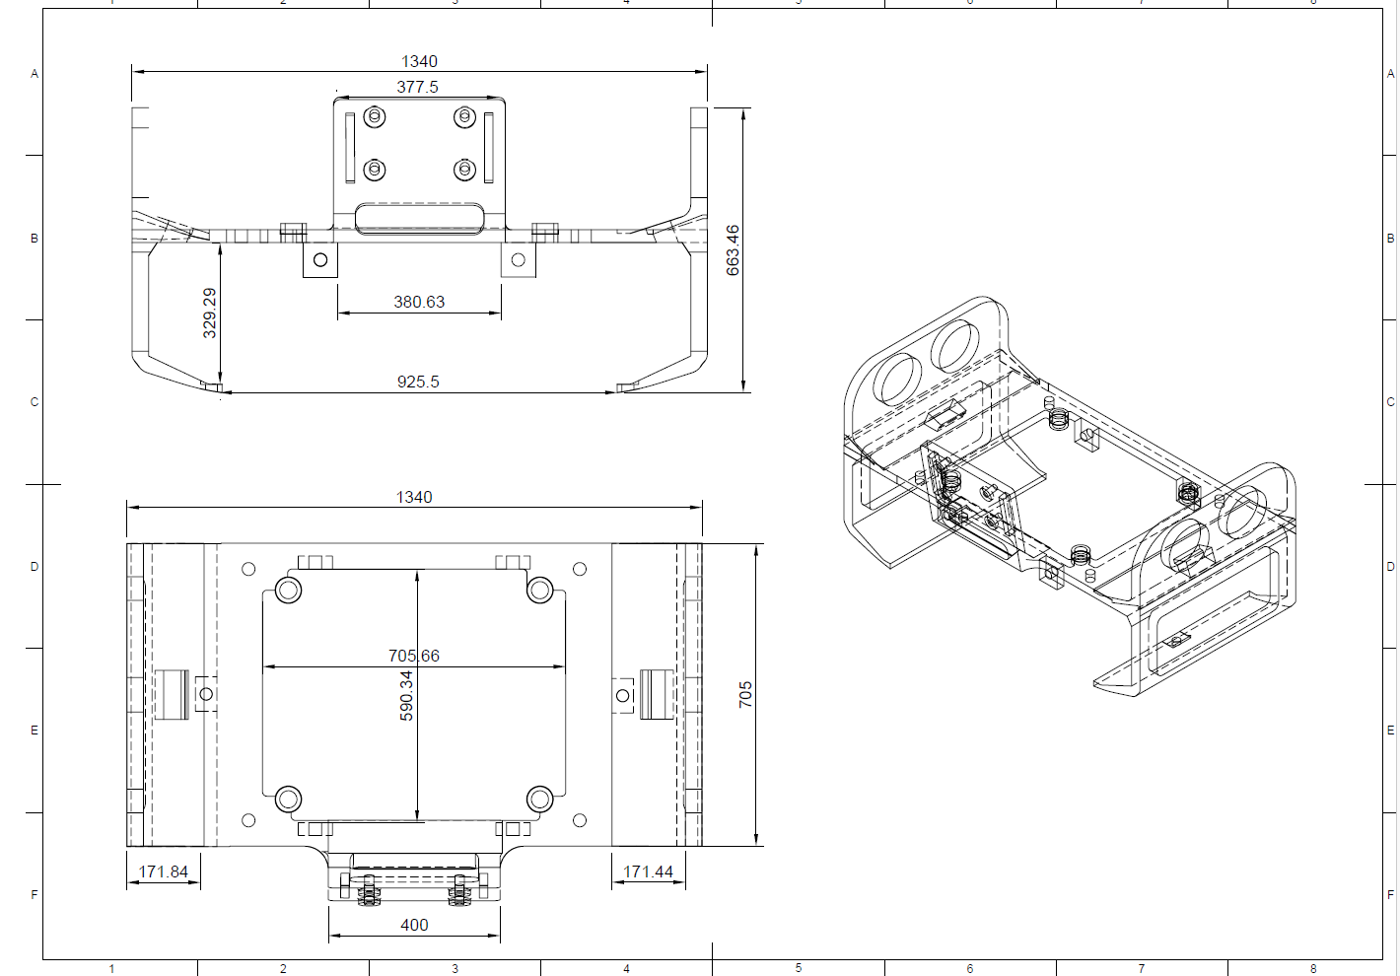
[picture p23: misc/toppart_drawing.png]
  
</p>

**Specifications:**
- **Sensor:** Sony IMX219 (8-megapixel sensor)
- **Resolution:** 3280 × 2464 pixels (still), 1920 × 1080 @ 30fps (video)
- **Field of View:** 62.2° × 48.8°
- **Interface:** CSI (Camera Serial Interface) direct to Raspberry Pi 5
- **Focus:** Fixed focus optimized for 1-2 meter range

**Mounting Position:**
The camera is mounted at the front of the chassis, angled slightly downward (approximately 15-20°) to capture:
- **Turn lines** (orange and blue) on the track surface
- **Traffic signs** (red and green pillars) at 1-2 meters distance
- **Parking walls** (magenta markers)

**Vision Processing:**
The Pi 5 runs **OpenCV** (Python) for real-time image processing:
- **Color detection** using HSV color space (more robust than RGB under varying lighting)
- **Bounding box creation** around detected objects (obstacles, parking walls)
- **Centroid calculation** for determining object position and distance
- **Real-time frame processing** at 30 fps for responsive obstacle avoidance

**Cost:** 33 CAD

---

## RPLidar A2M12 

<!-- ⚠️⚠️⚠️ REMINDER: ADD RPLIDAR MOUNTING PHOTO AND SCANNING VISUALIZATION ⚠️⚠️⚠️ -->
<p align="center">
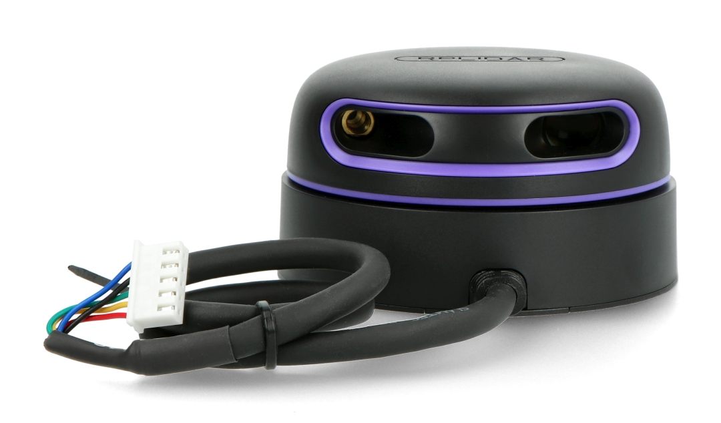
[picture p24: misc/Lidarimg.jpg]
  
</p>

### Lidar Mount Drawing

<p align="center">
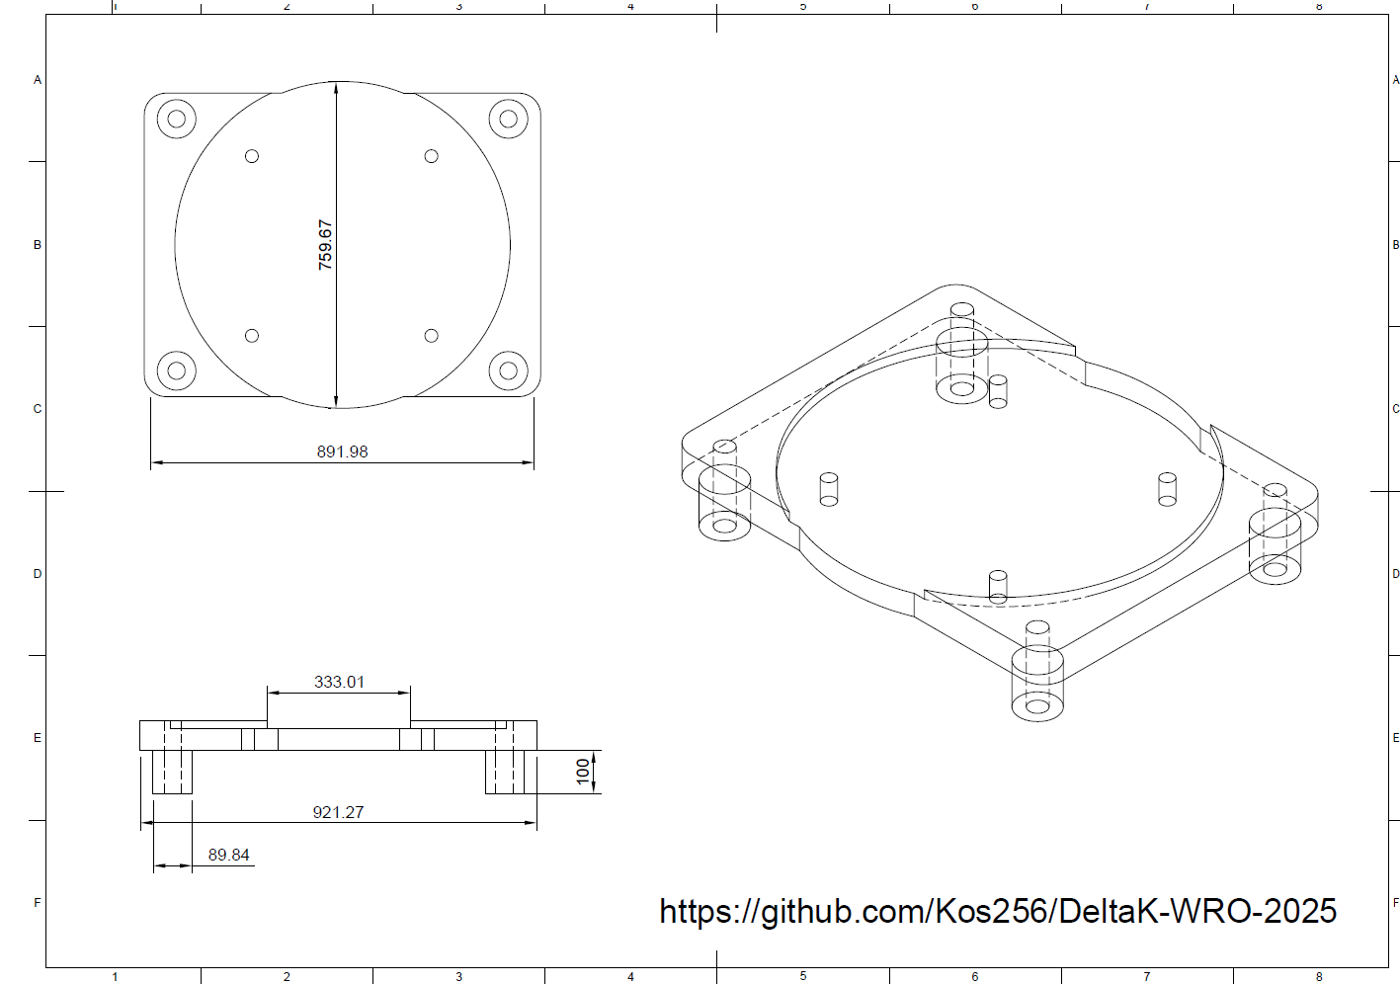
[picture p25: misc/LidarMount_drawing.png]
  
</p>

The **RPLidar A2M12** is Delta Bot's primary navigation sensor, providing 360-degree environmental mapping.

**Technical Specifications:**
- **Range:** 0.15m - 12m
- **Scan Rate:** 5.5Hz - 10Hz (adjustable)
- **Angular Resolution:** 0.9° (400 samples per 360° scan)
- **Sample Rate:** 4000 samples/second
- **Interface:** USB connection to Raspberry Pi 5
- **Power:** 5V/2A
- **Weight:** ~190g (including motor and mounting bracket)

**Mounting Position:**
The LiDAR is mounted on an elevated tower at the center of the robot to ensure:
- **Unobstructed 360° view** (no chassis components block the laser)
- **Correct height** to detect obstacles and walls without floor interference
- **Stability** during high-speed maneuvers (no vibration-induced noise)

**Role in Navigation Strategy:**

1. **Wall Mapping:** Creates a real-time 2D map of the track walls, allowing the robot to understand the track boundaries

2. **Path Planning:** Identifies available space for navigation:
   - Detects gaps in walls for turn detection
   - Calculates safe distances from obstacles
   - Determines parking space location and dimensions

3. **Collision Prevention:** Continuously monitors all directions, preventing collisions with:
   - Track walls
   - Traffic sign obstacles
   - Other unexpected objects

4. **Distance Measurement:** Provides precise distance readings in all directions, used for:
   - Maintaining safe distance from walls during straight-line navigation
   - Measuring distance to obstacles before avoidance maneuvers
   - Confirming parking space dimensions

**Data Processing:**
The LiDAR generates approximately **4000 distance measurements per second**. The Raspberry Pi 5 processes this data stream to:
- Filter noise and outliers
- Build occupancy grid maps
- Identify clusters (walls, obstacles)
- Calculate free space for path planning

**Why LiDAR was Essential:**
Our early ultrasonic-only approach failed because:
- Ultrasonic sensors have narrow fields of view (~15°)
- Multiple ultrasonics cause interference
- Cannot create comprehensive maps

The LiDAR provides complete environmental awareness that ultrasonics simply cannot match.

**Cost:** 210 CAD

---

## LSM6DSOX IMU 

<!-- ⚠️⚠️⚠️ REMINDER: ADD IMU MOUNTING PHOTO ⚠️⚠️⚠️ -->
<p align="center">
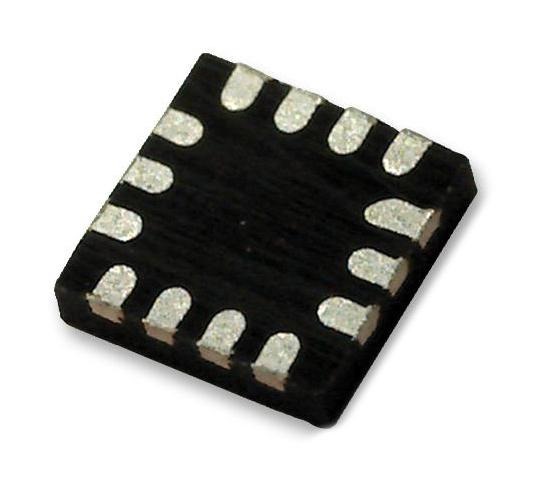
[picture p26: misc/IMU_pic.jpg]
LSM6DSOX IMU
  
</p>

**Technical Specifications:**
- **Chip:** STMicroelectronics LSM6DSOX
- **Gyroscope Range:** ±125/±250/±500/±1000/±2000 dps (degrees per second)
- **Accelerometer Range:** ±2/±4/±8/±16 g
- **Interface:** I2C (integrated into XRP board)
- **Update Rate:** Up to 6.66 kHz (configurable)
- **Precision:** 16-bit ADC resolution

**Integrated with XRP Board:**
The LSM6DSOX comes pre-soldered and integrated with the XRP Controller Board, eliminating the need for separate wiring and mounting.

**Role in Navigation:**

The IMU is critical for **precise turning and orientation tracking**:

1. **Gyroscope (Primary Use):** Measures angular velocity (rotation rate) around the Z-axis (vertical axis of the robot). By integrating angular velocity over time, we calculate the robot's current heading angle.

2. **Turn Angle Calculation:** 
   - Robot starts at 0° heading
   - IMU integrates gyroscope data to track cumulative angle change
   - When turning 90° at corners, IMU ensures exact 90° rotation (not 87° or 93°)
   - Critical for maintaining orientation after multiple turns

3. **Drift Compensation:** 
   - All IMUs experience drift (small errors accumulate over time)
   - We calibrate drift during initialization
   - Periodic corrections using LiDAR wall alignment prevent long-term drift

4. **Accelerometer (Secondary Use):**
   - Detects sudden impacts or collisions
   - Monitors robot tilt (ensures robot is level)
   - Validates motion (confirms robot is actually moving when motors are commanded)

**Why IMU was Essential:**
Early attempts using only encoder-based dead reckoning for turns resulted in:
- Cumulative angle errors (small steering imperfections compound)
- Wheel slip causing angle miscalculations
- Inability to recover from collisions or unexpected pushes

The IMU provides **absolute angular velocity measurement** independent of wheel motion, ensuring turns are always precise.

**Cost:** Included with XRP Board (60 CAD total)

---

## HC-SR04 Ultrasonic Sensor 

<!-- ⚠️⚠️⚠️ REMINDER: ADD ULTRASONIC SENSOR MOUNTING PHOTO ⚠️⚠️⚠️ -->
<p align="center">
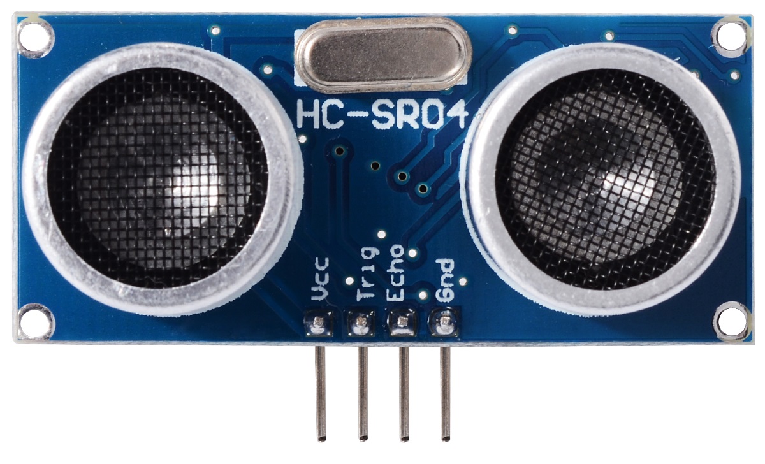
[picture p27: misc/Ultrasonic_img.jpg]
HC-SR04 Ultrasonic Sensor
  
</p>

**Technical Specifications:**
- **Operating Voltage:** 5V
- **Range:** 2cm - 400cm
- **Accuracy:** ±3mm
- **Measuring Angle:** 15° cone
- **Trigger Pulse:** 10µs
- **Echo Pulse:** Proportional to distance

**Mounting Position:**
Front-facing, centered on the chassis

**Role in System:**
The ultrasonic sensor serves as a **backup/redundancy sensor** to the LiDAR:

1. **Front Obstacle Detection:** Quickly detects objects directly in front
2. **LiDAR Validation:** Cross-checks LiDAR readings for critical front obstacles
3. **Close-Range Safety:** Ultrasonic performs better than LiDAR at very close range (<15cm)
4. **Emergency Stop:** Can trigger emergency braking if front obstacle is too close

**Why Backup Sensor?**
During nationals, when our ultrasonic wiring short-circuited, the robot could still function using LiDAR alone. However, the ultrasonic provides:
- Faster response time for front obstacles (simpler processing than LiDAR)
- Redundancy in case of LiDAR failure
- Confidence in front-facing decisions

**Cost:** 14 CAD

---

## Motor Encoder 

<!-- ⚠️⚠️⚠️ REMINDER: ADD ENCODER INTEGRATION PHOTO ⚠️⚠️⚠️ -->

**Specifications:**
- **Type:** DG01D-E Quadrature Encoder
- **Resolution:** [Specify pulses per revolution]
- **Output:** Two-channel quadrature signal (A and B phases)
- **Interface:** Connected to XRP board encoder inputs

**Integration:**
The encoder is integrated directly into our custom motor assembly (see [Custom Motor Design](#custom-motor-design)), providing precise feedback on wheel rotation.

**Role in Odometry:**

1. **Distance Measurement:** By counting encoder pulses and knowing wheel diameter, we calculate exact distance traveled:
   ```
   Distance = (Encoder Pulses / Pulses per Revolution) × Wheel Circumference
   ```

2. **Speed Control:** Real-time encoder feedback enables closed-loop speed control:
   - Measure actual wheel speed
   - Compare to target speed
   - Adjust motor PWM to maintain consistent speed

3. **Position Tracking:** Combined with IMU heading, encoder distance enables dead reckoning:
   - Track X, Y position on the field
   - Validate LiDAR-based localization
   - Detect wheel slip (encoder shows no movement despite motor running)

4. **Calibration:** Encoder data helps calibrate:
   - Wheel diameter variations
   - Motor performance curves
   - Acceleration/deceleration profiles

**Encoder Processing:**
The XRP board's RP2040 microcontroller handles encoder counting in hardware, preventing missed pulses even during intensive processing tasks.

**Cost:** 23 CAD (including motor modifications)

---

## Power System 

<!-- ⚠️⚠️⚠️ REMINDER: ADD POWER SYSTEM DIAGRAM AND BATTERY PLACEMENT PHOTOS ⚠️⚠️⚠️ -->
<p align="center">
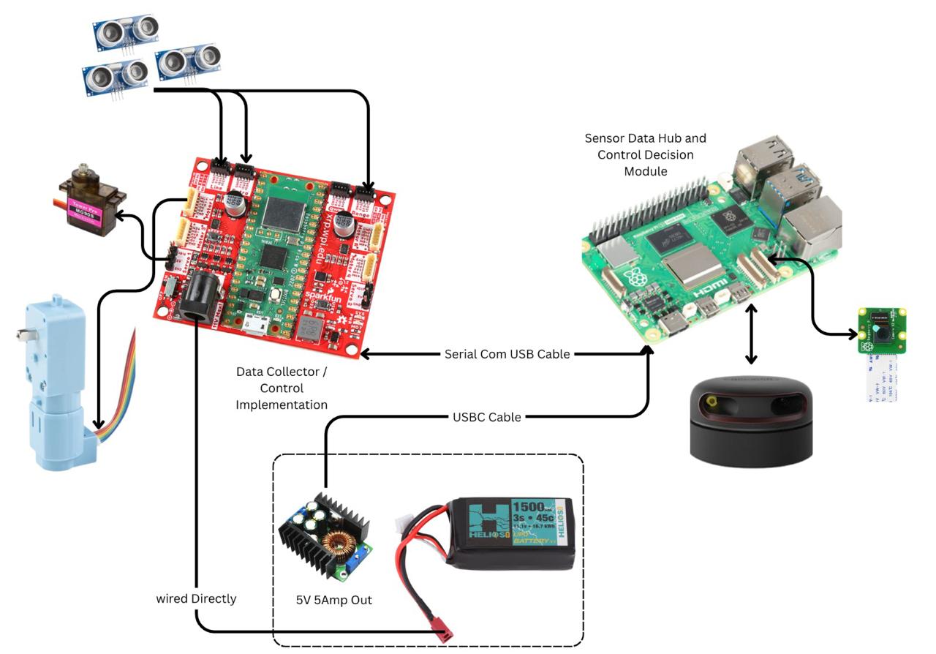
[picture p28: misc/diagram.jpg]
Power System Layout
  
</p>

Delta Bot's power system is designed for **high capacity, voltage flexibility, and safety**.

### Battery Configuration

**3× 1500mAh LiPo Batteries**
- **Voltage:** 7.4V (2S configuration) per battery
- **Capacity:** 1500mAh per battery = 4500mAh total
- **Discharge Rate:** 25C (sufficient for motor current spikes)
- **Configuration:** Can be wired in parallel (7.4V, 4500mAh) or series (22.2V, 1500mAh) depending on power requirements
- **Weight:** ~120g total
- **Cost:** 18 CAD × 3 = 54 CAD

<!-- ⚠️⚠️⚠️ REMINDER: ADD BATTERY RUNTIME TEST DATA ⚠️⚠️⚠️ -->

**Battery Life:**
- Estimated runtime: [X] minutes of continuous operation
- Competition run duration: ~3-5 minutes (well within capacity)
- Safety margin: Batteries are never depleted below 20% to preserve lifespan

### Voltage Regulation

Different components require different voltages, necessitating a multi-stage voltage regulation system:

**Voltage Regulator System (Cost: 50 CAD)**

1. **7.4V → 5V Step-Down Regulator:**
   - Powers: Raspberry Pi 5 (5V/5A requirement)
   - Type: High-efficiency buck converter
   - Current Capacity: 5A continuous

2. **7.4V → 5V Step-Down Regulator (Secondary):**
   - Powers: RPLidar A2M12 (5V/2A requirement)
   - Separate regulator prevents LiDAR current spikes from affecting Pi 5

3. **7.4V Direct:**
   - Powers: XRP board (accepts 7.4V input directly)
   - XRP board has onboard regulators for its components

4. **7.4V → [Motor Voltage] Regulator:**
   - Powers: Custom drive motor
   - May include step-up converter if higher voltage needed

<!-- ⚠️⚠️⚠️ REMINDER: ADD DETAILED POWER DISTRIBUTION DIAGRAM ⚠️⚠️⚠️ -->

### Power Distribution

**Pi HAT (Cost: 30 CAD):**
A custom power distribution board (Pi HAT) mounts directly on the Raspberry Pi 5's GPIO header, providing:
- Clean 5V power delivery to Pi 5
- Fused protection circuits
- Power switching (on/off control)
- LED status indicators

### Safety Features

1. **Fused Connections:** Each major component has inline fuses to prevent damage from short circuits
2. **Low-Voltage Cutoff:** Software monitors battery voltage and prevents over-discharge
3. **Current Monitoring:** Detect abnormal current draw (stalled motor, short circuits)
4. **Emergency Stop:** Physical button to immediately cut all power

---

# Software Architecture 

Delta Bot's software is designed as a modular, multi-threaded system where each subsystem operates independently while sharing data through a central coordination layer.

## Code Structure 

<!-- ⚠️⚠️⚠️ REMINDER: ADD SOFTWARE ARCHITECTURE DIAGRAM ⚠️⚠️⚠️ -->

### File Organization

```
delta-bot/
│
├── main.py                  # Main control loop and state machine
├── config.py                # Configuration parameters and constants
│
├── sensors/
│   ├── lidar.py            # RPLidar data acquisition and processing
│   ├── camera.py           # PiCam2 image capture and preprocessing
│   ├── imu.py              # IMU data reading and fusion
│   ├── ultrasonic.py       # Ultrasonic distance measurement
│   └── encoder.py          # Motor encoder position tracking
│
├── vision/
│   ├── color_detection.py  # HSV-based color threshold detection
│   ├── obstacle_detection.py  # Red/green traffic sign detection
│   ├── parking_detection.py   # Magenta parking wall detection
│   └── line_detection.py      # Orange/blue turn line detection
│
├── navigation/
│   ├── mapping.py          # LiDAR-based map building
│   ├── path_planning.py    # Route calculation and obstacle avoidance
│   ├── localization.py     # Position estimation using sensor fusion
│   └── turn_control.py     # Precise turning using IMU
│
├── control/
│   ├── motor_control.py    # Motor speed and direction control
│   ├── servo_control.py    # Steering angle control
│   └── pid_controller.py   # PID implementation for stable control
│
├── communication/
│   └── xrp_interface.py    # Serial UART communication with XRP board
│
└── utils/
    ├── data_logger.py      # Performance data logging
    └── helpers.py          # Utility functions
```

### Programming Languages

- **Python 3.11:** All Raspberry Pi 5 code (sensor processing, vision, navigation, high-level control)
- **MicroPython:** XRP board code (motor drivers, servo control, encoder reading, IMU interfacing)

### Libraries Used

**Raspberry Pi 5 (Python):**
- **OpenCV (cv2):** Computer vision and image processing
- **rpicam2:** Raspberry Pi camera interface
- **NumPy:** Numerical computations and array operations
- **Pillow (PIL):** Image manipulation
- **regex (re):** Pattern matching and data parsing
- **serial (PySerial):** UART communication with XRP board
- **rplidar:** LiDAR data acquisition library

**XRP Board (MicroPython):**
- **XRPLib:** Official XRP board library for motor control, servo control, and sensor interfaces
- **machine:** Low-level hardware control (UART, I2C, PWM)

---

## Computer Vision 

<!-- ⚠️⚠️⚠️ REMINDER: ADD COMPUTER VISION PROCESSING PIPELINE DIAGRAM ⚠️⚠️⚠️ -->

Delta Bot's vision system uses **HSV color space** instead of RGB for robust color detection under varying lighting conditions.

### Color Detection Pipeline

1. **Image Capture:** PiCam2 captures 1920×1080 frames at 30fps

2. **Color Space Conversion:** Convert BGR (OpenCV default) → HSV
   - **Hue:** Color type (0-180° in OpenCV)
   - **Saturation:** Color intensity (0-255)
   - **Value:** Brightness (0-255)

3. **Color Thresholding:** Define HSV ranges for each color:

<!-- ⚠️⚠️⚠️ REMINDER: ADD YOUR ACTUAL HSV THRESHOLD VALUES HERE ⚠️⚠️⚠️ -->

```python
# Example HSV thresholds (adjust based on testing)
RED_LOWER = np.array([0, 120, 70])
RED_UPPER = np.array([10, 255, 255])

GREEN_LOWER = np.array([40, 50, 50])
GREEN_UPPER = np.array([80, 255, 255])

ORANGE_LOWER = np.array([10, 100, 100])
ORANGE_UPPER = np.array([25, 255, 255])

BLUE_LOWER = np.array([100, 150, 0])
BLUE_UPPER = np.array([130, 255, 255])

MAGENTA_LOWER = np.array([140, 50, 50])
MAGENTA_UPPER = np.array([170, 255, 255])
```

4. **Morphological Operations:** Clean up noise
   - Erosion: Remove small false positives
   - Dilation: Fill gaps in detected regions

5. **Contour Detection:** Find connected regions of detected colors

6. **Bounding Box Creation:** Draw rectangles around detected objects

7. **Centroid Calculation:** Find center point (x, y) of each bounding box

8. **Object Classification:** Determine object type based on:
   - Color (red/green obstacle, orange/blue line, magenta parking)
   - Size (filter out small noise)
   - Shape (aspect ratio)
   - Position in frame

### Frame Processing Rate

- **Target:** 30 fps (real-time)
- **Actual:** Achieved on Raspberry Pi 5 (unlike Pi 4 which struggled)
- **Latency:** <50ms from capture to decision

---

## Sensor Fusion 

<!-- ⚠️⚠️⚠️ REMINDER: ADD SENSOR FUSION DIAGRAM SHOWING HOW DATA COMBINES ⚠️⚠️⚠️ -->

Delta Bot combines data from five sensors to build a comprehensive understanding of its environment:

### Multi-Sensor Integration

1. **LiDAR (Primary Mapping):**
   - Builds 2D occupancy grid of environment
   - Detects walls, obstacles, and free space
   - Provides 360° awareness

2. **Camera (Object Recognition):**
   - Identifies traffic sign colors (red/green)
   - Detects turn lines (orange/blue)
   - Locates parking walls (magenta)

3. **IMU (Orientation):**
   - Tracks robot heading (angle)
   - Measures angular velocity during turns
   - Detects unexpected rotations

4. **Encoder (Odometry):**
   - Measures distance traveled
   - Calculates speed
   - Detects wheel slip

5. **Ultrasonic (Backup):**
   - Validates front obstacle detection
   - Close-range safety checks

### Complementary Strengths

Each sensor compensates for others' weaknesses:
- **LiDAR provides spatial awareness** but can't identify colors → Camera adds color recognition
- **Camera identifies objects** but can't measure precise distances → LiDAR provides exact measurements
- **Encoder tracks distance** but accumulates error over time → LiDAR corrects position drift
- **IMU tracks heading** but drifts over time → LiDAR wall alignment corrects drift

---

## Communication Protocol 

### Raspberry Pi 5 ↔ XRP Board (UART Serial)

<!--
- **Pi 5 TX** (GPIO 14) → **XRP RX**
- **Pi 5 RX** (GPIO 15) → **XRP TX**
-->
The XRP board is connected to one of the USB 3.0 ports on the Pi 5 via a micro-usb cable. This is the main serial connection between the hardware controller and the main processor.
- **Baud Rate:** 230400
- **Protocol:** Plain text commands with basic formatting.

**Command Structure:**

**Pi 5 → XRP (Commands):**
```
motor: <speed> (Set motor speed from -100 to 100)
servo: <angle> (Send a servo angle from 0 to 180 which sets a steering angle from -45 to 45)

Example: "<motor: 80; servo: -1>"
Move forward at 80% speed and keep servo free/inactive
```

**XRP → Pi 5 (Responses):**
The responding input data is structured as followed:
```py
outputData = {
    'i': i,
    # 'dist': rangefinder.distance(),
    # 'accel': f"{imu.get_acc_x()}, {imu.get_acc_y()}, {imu.get_acc_z()}",
    # 'gyro': f"{imu.get_roll()}, {imu.get_heading()}, {imu.get_yaw()}",
    # 'gyrorate': f"{imu.get_gyro_x_rate()}, {imu.get_gyro_y_rate()}, {imu.get_gyro_z_rate()}"
    'accel': f"{imu.get_acc_x()}, {imu.get_acc_y()}",
    'gyroHeading': imu.get_heading(),
    # 'gyroHeadingRate': imu.get_gyro_y_rate()
    'distL': usLeft.distance(),
    'distR': usRight.distance()
}
```
A lot of desirable but unnecessary sensor values are commented out, just in case we need to send them.
```
accel: <x> <y>          (Provides the accelerometer's X and Y acceleration values)
ENCODER:<position>,<speed>
gyroHeading: <heading>  (Provides the heading of the robot reported by the onboard gyro sensor)
distL: <distance_cm>    (Reports left ultrasonic sensor's distance in centimeters)
distR: <distance_cm>    (Reports right ultrasonic sensor's distance in centimeters)
ACK:<command>       # Acknowledge command received
```

This conversation between the Pi 5 and XRP happen without thread blocking, which means sensor values can be fetched and motor instructions can be sent at any time.

**Error Handling:**
There isn't much error handling as there's not many factors of failure here, since the XRP's code is single threaded and stable. Here's what *is* checked:
- Ignore input if command's syntax is invalid.
- Automatic reconnection on communication failure

---

# Obstacle Management 

Delta Bot's navigation strategy evolved through extensive testing to balance speed, accuracy, and robustness.

## Qualification Round Strategy 

<!-- ⚠️⚠️⚠️ REMINDER: ADD QUALIFICATION ROUND STRATEGY DIAGRAM ⚠️⚠️⚠️ -->

**Objective:** Complete 3 laps as fast as possible, turning at orange or blue corner lines.

### Algorithm Overview

1. **Track Mapping Phase (First Lap):**
   - Use LiDAR to build a complete map of track boundaries
   - Identify wall positions and track dimensions
   - Calculate optimal racing line (path farthest from walls for maximum speed)

2. **Turn Detection:**
   - LiDAR detects gaps in walls (corners)
   - No reliance on color detection in qualification round
   - Turn trigger: LiDAR identifies corner geometry

3. **Turning Sequence:**
   - Approach corner at moderate speed
   - Slow down slightly before turn
   - Use IMU to execute precise 90° turn
   - Accelerate out of corner

4. **Straight-Line Navigation:**
   - Maintain center of track using LiDAR wall distance measurements
   - Simulated PID keeps robot straight using IMU heading
   - Encoder confirms distance traveled

5. **Lap Counting:**
   - Track number of 90° turns completed (12 turns = 3 laps)
   - After 12 turns, proceed to finish area

### Performance Metrics

- **Best Lap Time:** 14 seconds
- **Consistency:** [Add consistency data if available]
- **Reliability:** Successfully completes 3 laps in >X% of attempts

---

## Obstacle Round Strategy 

<!-- ⚠️⚠️⚠️ REMINDER: ADD OBSTACLE AVOIDANCE STRATEGY DIAGRAM WITH EXAMPLES ⚠️⚠️⚠️ -->

**Objective:** Complete 3 laps while avoiding red and green traffic signs, with a mandatory U-turn if the last obstacle before lap 3 is red.

### Detection System

1. **Camera Continuously Scans** for red and green objects
2. **HSV Color Filtering** isolates potential obstacles
3. **Bounding Box Creation** around detected colors
4. **Centroid Calculation** determines obstacle center position
5. **Nearest Obstacle Selection:** Robot prioritizes closest detected obstacle

### Avoidance Decision Logic

```
IF red obstacle detected:
    Turn RIGHT to avoid
    
IF green obstacle detected:
    Turn LEFT to avoid
    
IF no obstacles detected:
    Continue straight using qualification round navigation
```

### Avoidance Execution

1. **LiDAR Validates Available Space:**
   - Check if right side (for red) or left side (for green) has sufficient clearance
   - Measure distance to walls in avoidance direction
   - Ensure no collision with track boundaries

2. **Calculate Avoidance Angle:**
   - Based on obstacle distance and position
   - Dynamically adjusted using camera centroid
   - Confirmed safe by LiDAR

3. **IMU-Controlled Avoidance Maneuver:**
   - Turn at calculated angle
   - Maintain angle while passing obstacle
   - Return to center line after clearing obstacle

4. **Encoder Confirms Distance:**
   - Track distance traveled during avoidance
   - Ensure full clearance before returning to center

### U-Turn Logic

**U-Turn Trigger Conditions:**
```
IF (lap_count == 2) AND (obstacles_remaining == 1) AND (last_obstacle == RED):
    Execute U-turn sequence
    Reverse direction for lap 3
```

**U-Turn Execution:**
1. Complete avoidance of final red obstacle
2. Move forward additional distance to clear obstacle zone
3. Execute 180° turn using IMU (precise angle critical)
4. Update internal direction variable (clockwise ↔ counterclockwise)
5. Continue lap 3 in opposite direction

**Challenge:** Accurately counting obstacles and identifying the "last" obstacle before lap 3 requires:
- Reliable obstacle detection (no false positives/negatives)
- Accurate lap counting (based on turn counting)
- Robust logic to handle edge cases (obstacles near corners)

### Performance Metrics

- **Obstacle Avoidance Success Rate:** [Add success percentage]
- **U-Turn Success Rate:** [Add success percentage]
- **Best Obstacle Round Score:** 10.0 (14 points)

---

## Parking Challenge 

<!-- ⚠️⚠️⚠️ REMINDER: ADD PARKING CHALLENGE SEQUENCE DIAGRAMS ⚠️⚠️⚠️ -->

**Objective:** After completing obstacle rounds, locate and parallel park between magenta walls.

### Parking Detection

1. **Camera Scans for Magenta Color:**
   - Continuously search for magenta HSV threshold matches
   - Create bounding boxes around detected magenta regions

2. **LiDAR Detects Gap:**
   - Measure wall distances in all directions
   - Identify gap in walls (parking space opening)
   - Measure gap width to confirm sufficient space

3. **Cross-Validation:**
   - Both camera (magenta walls) AND LiDAR (gap) must confirm parking space
   - Reduces false positives (random magenta objects)

### Parking Sequence

**Phase 1: Positioning**
1. Drive parallel to parking space
2. Position robot so parking space is to the side
3. Stop when parking space is aligned with robot center

**Phase 2: Entry Turn**
1. Turn steering toward parking space (IMU-controlled angle)
2. Drive forward into parking space at slow speed
3. LiDAR monitors distance to back wall

**Phase 3: Alignment**
1. Straighten steering (servo to center position)
2. Continue forward until LiDAR detects appropriate distance from back wall
3. Stop precisely between front and back magenta walls

**Phase 4: Final Positioning**
1. Minor adjustments if needed (reverse slightly, straighten)
2. Confirm parallel alignment with walls using IMU
3. Complete stop - parking successful!

### Challenges Faced

<!-- ⚠️⚠️⚠️ REMINDER: ADD DETAILS ABOUT PARKING CHALLENGES AND WHY NOT SUCCESSFUL YET ⚠️⚠️⚠️ -->

**Current Status:** Parking challenge not yet successfully completed in competition.

**Primary Difficulties:**
- [Add specific challenges: magenta detection reliability, alignment precision, timing, etc.]
- [Explain what needs improvement]

**Planned Improvements:**
- [List specific improvements being developed]

---

# Code Implementation 

<!-- ⚠️⚠️⚠️ REMINDER: ADD ALL CODE SECTIONS BELOW WITH YOUR ACTUAL CODE ⚠️⚠️⚠️ -->
<!-- For each section, add the relevant Python/MicroPython code with detailed comments -->

## Main Control Loop 

The main control loop implements a state machine to handle different phases of the competition.

```python
# ⚠️⚠️⚠️ ADD YOUR main.py CODE HERE ⚠️⚠️⚠️
# Include: State machine structure, main loop, state transitions

# Example structure (replace with your actual code):
"""
import time
from sensors import lidar, camera, imu
from navigation import path_planning, turn_control
from control import motor_control, servo_control

class RobotState:
    INIT = 0
    QUALIFICATION = 1
    OBSTACLE_AVOIDANCE = 2
    PARKING_SEARCH = 3
    PARKING = 4
    COMPLETE = 5

def main():
    # Initialize all systems
    state = RobotState.INIT
    
    while True:
        if state == RobotState.INIT:
            # Initialization code
            pass
            
        elif state == RobotState.QUALIFICATION:
            # Qualification round navigation
            pass
            
        elif state == RobotState.OBSTACLE_AVOIDANCE:
            # Obstacle detection and avoidance
            pass
            
        elif state == RobotState.PARKING_SEARCH:
            # Search for parking space
            pass
            
        elif state == RobotState.PARKING:
            # Execute parking maneuver
            pass
            
        elif state == RobotState.COMPLETE:
            # Stop all motors
            break

if __name__ == "__main__":
    main()
"""
```

---

## LiDAR Mapping 

LiDAR data processing creates a 2D occupancy grid map of the environment.

```python
# ⚠️⚠️⚠️ ADD YOUR sensors/lidar.py CODE HERE ⚠️⚠️⚠️
# Include: LiDAR initialization, data acquisition, map building, wall detection

# Example structure (replace with your actual code):
"""
from rplidar import RPLidar
import numpy as np

class LidarProcessor:
    def __init__(self, port='/dev/ttyUSB0'):
        self.lidar = RPLidar(port)
        self.scan_data = []
        
    def start_scanning(self):
        # Start LiDAR motor and scanning
        pass
        
    def get_scan(self):
        # Retrieve one complete 360° scan
        # Returns: list of (angle, distance) tuples
        pass
        
    def build_map(self, scans):
        # Convert scan data to occupancy grid
        pass
        
    def detect_walls(self, scan):
        # Identify wall segments from scan data
        pass
        
    def detect_gaps(self, scan):
        # Find gaps in walls (corners, parking space)
        pass
"""
```

---

## Color Detection 

Camera-based color detection for obstacles, lines, and parking walls.

```python
# ⚠️⚠️⚠️ ADD YOUR vision/color_detection.py CODE HERE ⚠️⚠️⚠️
# Include: HSV thresholding, contour detection, bounding boxes, centroid calculation

# Example structure (replace with your actual code):
"""
import cv2
import numpy as np
from picamera2 import Picamera2

class ColorDetector:
    def __init__(self):
        self.camera = Picamera2()
        self.camera.configure(self.camera.create_preview_configuration())
        self.camera.start()
        
        # HSV thresholds for different colors
        self.RED_LOWER = np.array([0, 120, 70])
        self.RED_UPPER = np.array([10, 255, 255])
        # ... (add all color thresholds)
        
    def capture_frame(self):
        # Capture image from camera
        pass
        
    def detect_color(self, frame, lower_hsv, upper_hsv):
        # Detect specific color in frame
        # Returns: bounding boxes and centroids
        pass
        
    def detect_obstacles(self, frame):
        # Detect red and green traffic signs
        pass
        
    def detect_parking_walls(self, frame):
        # Detect magenta parking walls
        pass
        
    def detect_turn_lines(self, frame):
        # Detect orange and blue turn lines
        pass
"""
```

---

## IMU Integration 

IMU data processing for precise heading tracking and turn execution.

```python
# ⚠️⚠️⚠️ ADD YOUR sensors/imu.py CODE HERE ⚠️⚠️⚠️
# Include: IMU initialization, gyroscope reading, angle integration, drift compensation

# Example structure (replace with your actual code):
"""
import time

class IMUProcessor:
    def __init__(self, xrp_interface):
        self.xrp = xrp_interface
        self.current_heading = 0.0
        self.last_update_time = time.time()
        
    def calibrate_drift(self):
        # Measure and compensate for gyroscope drift
        pass
        
    def update_heading(self):
        # Read angular velocity from IMU
        # Integrate to calculate current heading
        pass
        
    def get_heading(self):
        # Return current heading in degrees (0-360)
        return self.current_heading
        
    def turn_to_angle(self, target_angle):
        # Execute turn to reach target heading
        pass
        
    def reset_heading(self):
        # Reset heading to 0 (useful after calibration)
        self.current_heading = 0.0
"""
```

---

## Motor Control 

Motor speed and direction control with encoder feedback.

```python
# ⚠️⚠️⚠️ ADD YOUR control/motor_control.py CODE HERE ⚠️⚠️⚠️
# Include: Motor commands, speed control, encoder reading, distance calculation

# Example structure (replace with your actual code):
"""
class MotorController:
    def __init__(self, xrp_interface):
        self.xrp = xrp_interface
        self.wheel_diameter = 65  # mm
        self.encoder_pulses_per_rev = 360  # adjust to your encoder
        
    def set_speed(self, speed):
        # Set motor speed (-100 to 100)
        # Negative = reverse, Positive = forward
        command = f"MOTOR:{speed}\n"
        self.xrp.send_command(command)
        
    def stop(self):
        # Stop motor
        self.set_speed(0)
        
    def get_encoder_position(self):
        # Request encoder position from XRP
        pass
        
    def get_distance_traveled(self):
        # Calculate distance from encoder pulses
        pass
        
    def drive_distance(self, distance_cm, speed):
        # Drive forward/backward a specific distance
        pass
"""
```

---

## Obstacle Avoidance 

Complete obstacle detection and avoidance implementation.

```python
# ⚠️⚠️⚠️ ADD YOUR navigation/obstacle_avoidance.py CODE HERE ⚠️⚠️⚠️
# Include: Obstacle detection logic, avoidance angle calculation, execution

# Example structure (replace with your actual code):
"""
class ObstacleAvoider:
    def __init__(self, camera, lidar, imu, motor, servo):
        self.camera = camera
        self.lidar = lidar
        self.imu = imu
        self.motor = motor
        self.servo = servo
        
        self.obstacle_count = 0
        self.lap_count = 0
        
    def detect_nearest_obstacle(self):
        # Use camera to find nearest red or green obstacle
        # Returns: (color, centroid, distance)
        pass
        
    def calculate_avoidance_angle(self, obstacle_color, obstacle_position):
        # Calculate steering angle to avoid obstacle
        # Red → turn right, Green → turn left
        pass
        
    def validate_clearance(self, direction):
        # Use LiDAR to ensure safe clearance in avoidance direction
        pass
        
    def execute_avoidance(self, obstacle_color):
        # Complete avoidance maneuver
        pass
        
    def check_uturn_condition(self):
        # Determine if U-turn is required
        if self.lap_count == 2 and self.last_obstacle_color == 'RED':
            return True
        return False
        
    def execute_uturn(self):
        # Perform 180° turn using IMU
        pass
"""
```

---

# Robot Construction Guide 

This step-by-step guide will help you replicate Delta Bot from scratch.

## Prerequisites

**Tools Required:**
- 3D printer (we used Creality K1C)
- Soldering iron and solder
- Wire strippers
- Screwdrivers (Phillips and flathead)
- Hot glue gun (for temporary mounting/testing)
- Multimeter (for electrical testing)
- Computer with Arduino IDE and Python 3.11+

**Materials Required:**
- All components listed in [Cost Report](#cost-report)
- PLA+ filament (approximately 500g)
- Jumper wires (male-to-male, male-to-female, female-to-female)
- Heat shrink tubing
- Zip ties for cable management
- M3 screws and nuts (various lengths)

---

## Step 1: 3D Print All Components

**Printing Settings (Creality K1C):**
- **Material:** PLA+ and ABS
- **Layer Height:** 0.4mm + 0.6mm
- **Infill:** 20%
- **Print Speed:** 150mm/s
- **Supports:** Yes (for overhangs > 60°)
- **Brim:** Yes (for large flat parts to prevent warping)
---

## Step 2: Assemble Custom Motor

<!-- ⚠️⚠️⚠️ REMINDER: ADD DETAILED MOTOR ASSEMBLY PHOTOS FOR EACH STEP ⚠️⚠️⚠️ -->

1. **Disassemble TT Motor:**
   - Carefully open motor housing using small screwdriver
   - Remove internal components (keep organized!)
   - Note: Do not lose tiny gears or springs

2. **Prepare Encoder Integration:**
   - Position DG01D-E encoder on motor shaft
   - Ensure encoder disk aligns with optical sensors
   - Test encoder signals before permanent mounting

3. **Modify Motor Housing:**
   - Drill/file slots on both sides for axle pass-through
   - Ensure slots are aligned perfectly (use jig if possible)
   - Smooth all edges to prevent axle friction

4. **Reassemble Motor:**
   - Secure encoder with adhesive or screws
   - Carefully reassemble motor housing
   - Test motor rotation (should spin freely)

5. **Mount to Chassis:**
   - Position motor in custom motor mounts
   - Insert axle through both sides
   - Secure with M3 screws

**Testing:** Connect motor to XRP board and verify encoder readings before proceeding.

---

## Step 3: Assemble Steering System

<!-- ⚠️⚠️⚠️ REMINDER: ADD STEERING ASSEMBLY PHOTOS ⚠️⚠️⚠️ -->

1. **Attach Servo to Mount:**
   - Insert SG90 servo into `servo_mount.stl`
   - Secure with servo screws (usually included with servo)
   - Ensure servo rotates freely

2. **Install Front Axle Holders:**
   - Attach `front_axle_left.stl` and `front_axle_right.stl` to chassis
   - Insert smooth rod or axle pins for rotation

3. **Connect Steering Linkages:**
   - Attach `steering_linkage.stl` pieces to servo horn
   - Connect other ends to front axle holders
   - Adjust lengths for equal left/right steering

4. **Test Steering:**
   - Connect servo to XRP board
   - Test full range of motion (left, center, right)
   - Adjust linkages if needed

---

## Step 4: Install Wheels and Drivetrain

<!-- ⚠️⚠️⚠️ REMINDER: ADD WHEEL INSTALLATION PHOTOS ⚠️⚠️⚠️ -->

1. **Rear Wheels:**
   - Slide 65mm wheels onto rear axle (both sides of motor)
   - Secure with set screws or press-fit hubs
   - Ensure wheels are aligned and parallel

2. **Front Wheels:**
   - Attach 65mm wheels to front axle holders
   - Secure with appropriate fasteners
   - Test steering motion (wheels should turn together)

3. **Test Drive:**
   - Manually roll robot to check for friction
   - Wheels should roll smoothly without wobbling
   - Axles should not bind

---

## Step 5: Mount Electronics

<!-- ⚠️⚠️⚠️ REMINDER: ADD ELECTRONICS MOUNTING PHOTOS FOR EACH COMPONENT ⚠️⚠️⚠️ -->

### Raspberry Pi 5

1. Install NVMe SSD on bottom of Pi 5 (if using)
2. Mount Pi 5 to `pi5_mounting_tray.stl` using M2.5 screws
3. Attach Pi HAT for power distribution
4. Position tray on chassis (center, elevated for airflow)

### XRP Controller Board

1. Mount XRP board to `xrp_board_bracket.stl`
2. Position near motor for short motor wires
3. Secure with M3 screws

### RPLidar A2M12

1. Mount LiDAR to `lidar_mounting_plate.stl`
2. Attach plate to `lidar_tower.stl` (elevate LiDAR for clear view)
3. Secure tower to chassis center
4. Connect USB cable to Raspberry Pi 5

### PiCam2

1. Mount camera to `camera_mount.stl`
2. Angle mount ~15-20° downward
3. Position at front of chassis
4. Connect camera ribbon cable to Pi 5 CSI port

### HC-SR04 Ultrasonic Sensor

1. Insert sensor into `ultrasonic_bracket.stl`
2. Mount bracket at front of chassis (centered)
3. Wire to XRP board GPIO pins

### Batteries and Voltage Regulators

1. Place 3× LiPo batteries in `battery_compartment.stl`
2. Secure with velcro straps (allows easy removal)
3. Mount voltage regulators in `voltage_regulator_housing.stl`
4. Position regulators near batteries to minimize wire length

---

## Step 6: Wiring and Connections

<!-- ⚠️⚠️⚠️ REMINDER: ADD WIRING PHOTOS SHOWING ALL CONNECTIONS ⚠️⚠️⚠️ -->

**Power Distribution:**

1. **Battery to Voltage Regulators:**
   - Connect battery positive to main power switch
   - From switch, branch to all voltage regulators
   - Connect battery negative to common ground

2. **Voltage Regulator Outputs:**
   - 5V Regulator #1 → Raspberry Pi 5 (via Pi HAT)
   - 5V Regulator #2 → RPLidar A2M12
   - 7.4V Direct → XRP Board
   - 7.4V (or adjusted) → Motor driver on XRP

**Data Connections:**

3. **Raspberry Pi 5 Connections:**
   - PiCam2 → CSI camera port
   - RPLidar → USB 3.0 port
   - XRP Board → GPIO UART pins (TX/RX)

4. **XRP Board Connections:**
   - Custom Motor → Motor driver outputs
   - Motor Encoder → Encoder inputs (A, B channels)
   - SG90 Servo → Servo output pin
   - HC-SR04 Ultrasonic → GPIO (Trigger and Echo pins)
   - LSM6DSOX IMU → I2C (built into XRP board)

**Cable Management:**
- Route all wires through `wire_routing_channel.stl`
- Secure wires with `cable_clip.stl` pieces
- Use zip ties for additional security
- Leave some slack for maintenance access

---

## Step 7: Software Installation

### Raspberry Pi 5 Setup

1. **Install Raspberry Pi OS:**
   - Download Raspberry Pi OS (64-bit, desktop recommended)
   - Flash to NVMe SSD using Raspberry Pi Imager
   - Boot Pi 5 and complete initial setup

2. **Install Required Libraries:**
```bash
sudo apt update
sudo apt upgrade
sudo apt install python3-pip python3-opencv
pip3 install numpy pillow pyserial rplidar picamera2
```

3. **Clone Delta Bot Repository:**
```bash
git clone https://github.com/[your-username]/delta-bot-wro2025.git
cd delta-bot-wro2025
```

4. **Configure Permissions:**
```bash
# Add user to dialout group for serial access
sudo usermod -a -G dialout $USER

# Reboot for changes to take effect
sudo reboot
```

### XRP Board Setup

1. **Install XRPLib:**
   - Follow XRP official documentation for MicroPython setup
   - Connect XRP board via USB to computer
   - Upload MicroPython firmware

2. **Upload XRP Code:**
```bash
# Use Thonny IDE or similar to upload code
# Upload all files in /xrp_code/ directory
```

3. **Test XRP Functionality:**
   - Run motor test script
   - Verify servo response
   - Check IMU readings
   - Confirm encoder counting

---

## Step 8: Calibration and Testing

<!-- ⚠️⚠️⚠️ REMINDER: ADD CALIBRATION PROCEDURE PHOTOS/SCREENSHOTS ⚠️⚠️⚠️ -->

### IMU Calibration

1. Place robot on level surface
2. Run IMU calibration script
3. Let robot sit still for 30 seconds
4. Record drift compensation values

### Camera Calibration

1. Print color calibration targets (red, green, orange, blue, magenta)
2. Run color detection calibration script
3. Adjust HSV thresholds until colors detected reliably
4. Save calibration values to config file

### Motor Calibration

1. Measure exact wheel diameter
2. Count encoder pulses per revolution
3. Calculate distance per encoder pulse
4. Update configuration values

### Steering Calibration

1. Find servo center position (wheels straight)
2. Measure maximum left/right angles
3. Update servo angle limits in code

### LiDAR Calibration

1. Verify LiDAR mounting is level
2. Test 360° scanning for blind spots
3. Calibrate distance measurements against known distances

---

## Step 9: Initial Testing

<!-- ⚠️⚠️⚠️ REMINDER: ADD TESTING VIDEO OR PHOTOS ⚠️⚠️⚠️ -->

1. **Static Tests:**
   - Verify all sensors return data
   - Test motor forward/reverse
   - Test servo left/right
   - Check camera image capture

2. **Basic Movement:**
   - Drive forward 1 meter (measure accuracy)
   - Turn 90° using IMU (verify angle)
   - Test obstacle detection with colored objects

3. **Qualification Round Practice:**
   - Set up practice track
   - Run qualification algorithm
   - Measure lap times
   - Debug any issues

4. **Obstacle Round Practice:**
   - Add red/green traffic signs
   - Test obstacle detection and avoidance
   - Practice U-turn sequence
   - Refine avoidance angles

---

# Cost Report 

Complete breakdown of all expenses for Delta Bot's development.

## Electronic Components

| Component | Quantity | Unit Cost (CAD) | Total (CAD) |
|---|---|---|---|
| Raspberry Pi 5 (8GB) | 1 | 140.00 | 140.00 |
| PiCam2 | 1 | 33.00 | 33.00 |
| RPLidar A2M12 | 1 | 210.00 | 210.00 |
| XRP Controller Board (with LSM6DSOX IMU) | 1 | 60.00 | 60.00 |
| Brushed DC Motor + encoder | 1 | 23.00 | 23.00 |
| SG90 9g Micro Servo | 1 | 2.00 | 2.00 |
| HC-SR04 Ultrasonic Sensor | 1 | 14.00 | 14.00 |
| LiPo Battery (1500mAh, 7.4V) | 3 | 18.00 | 54.00 |
| Voltage Regulators (Step-up/Step-down) | 1 set | 50.00 | 50.00 |
| Raspberry Pi HAT | 1 | 30.00 | 30.00 |
| NVMe SSD (256GB) | 1 | 46.00 | 46.00 |
| **Electronics Subtotal** | | | **662.00** |

## Mechanical Components

| Component | Quantity | Unit Cost (CAD) | Total (CAD) |
|---|---|---|---|
| 65mm Tracked Wheels | 4 | 8.00 | 32.00 |
| Steel Axle Rods (2mm-5mm diameter) | Various | 15.00 | 15.00 |
| Bearings and Bushings | Set | 10.00 | 10.00 |
| M3 Screws and Nuts (assorted) | 100+ | 12.00 | 12.00 |
| M2.5 Screws (for Pi mounting) | 20 | 5.00 | 5.00 |
| **Mechanical Subtotal** | | | **74.00** |

## 3D Printing Materials

| Item | Quantity | Unit Cost (CAD) | Total (CAD) |
|---|---|---|---|
| PLA+ Filament (1kg spools) | 1 kg | 35.00 | 35.00 |
| Prototyping Filament (iterations) | 2 kg | 30.00 | 60.00 |
| Filament Dryer (Creality) | 1 | 65.00 | 65.00 |
| **3D Printing Subtotal** | | | **160.00** |

## Wiring and Electrical

| Component | Quantity | Unit Cost (CAD) | Total (CAD) |
|---|---|---|---|
| Jumper Wires (M-M, M-F, F-F sets) | 3 sets | 10.00 | 30.00 |
| Heat Shrink Tubing (assorted) | 1 set | 8.00 | 8.00 |
| Solder and Flux | 1 | 15.00 | 15.00 |
| Zip Ties (cable management) | 100 pack | 5.00 | 5.00 |
| USB Cables (various lengths) | 3 | 8.00 | 24.00 |
| Power Switch | 1 | 6.00 | 6.00 |
| **Wiring Subtotal** | | | **88.00** |

## Parts Tested But Not Used

| Component | Reason Removed | Cost (CAD) |
|---|---|---|
| Raspberry Pi 4 | Insufficient processing power | 120.00 |
| Arduino UNO | Poor camera support | 35.00 |
| PiCam v1.3 Wide Angle | Compatibility issues | 25.00 |
| L298N Motor Driver | Integrated into XRP board | 12.00 |
| 500 RPM DC Motor | Insufficient torque | 18.00 |
| LEGO Wheels | Insufficient grip | 20.00 |
| **Tested Parts Subtotal** | | **230.00** |

---

## Total Cost Summary

| Category | Cost (CAD) |
|---|---|
| Electronic Components | 662.00 |
| Mechanical Components | 74.00 |
| 3D Printing Materials | 160.00 |
| Wiring and Electrical | 88.00 |
| Parts Tested (Not Used) | 230.00 |
| Competition and Misc. | ~65.00 |
| **GRAND TOTAL** | **~1,279.00 + Tools** |

*Note: Costs are in Canadian Dollars (CAD). Prices may vary by region and retailer. Some tools may already be owned or borrowed, reducing total cost.*

---

# Future Improvements 

Based on six months of development and competition experience, we've identified several areas for enhancement:

## Hardware Improvements

1. **Ackermann Steering Geometry:**
   - Current parallel linkage causes minor tire scrub
   - Implementing true Ackermann would improve turning efficiency
   - Reduce tire wear during extended testing

2. **Brushless Motor Upgrade:**
   - More efficient than current brushed DC motor
   - Better thermal management for sustained performance
   - Longer lifespan and reduced maintenance

3. **Improved Camera Mount:**
   - Add adjustable tilt mechanism
   - Vibration dampening for sharper images
   - Wider field of view lens option

4. **Weight Distribution Optimization:**
   - Lower center of gravity for better handling
   - Balance weight more evenly front-to-back
   - Add adjustable ballast system

5. **Modular Sensor Mounting:**
   - Quick-release sensor mounts for rapid testing
   - Standardized mounting interfaces
   - Tool-free sensor angle adjustment

## Software Improvements

1. **Advanced Path Planning:**
   - Implement A* or RRT path planning algorithms
   - Dynamic re-routing when obstacles move
   - Predictive obstacle motion modeling

2. **Machine Learning Integration:**
   - Train neural network for robust obstacle detection
   - Adaptive color threshold learning
   - Automatic calibration using ML

3. **Sensor Fusion Enhancement:**
   - Kalman filter for combining sensor data
   - Better handling of conflicting sensor readings
   - Weighted sensor confidence based on conditions

4. **Parking Challenge Refinement:**
   - More precise alignment algorithms
   - Multi-point distance verification
   - Iterative positioning correction

5. **Code Optimization:**
   - Reduce processing latency
   - Parallel processing for sensor data
   - More efficient data structures

## Strategy Improvements

1. **Cleaner Turning:**
   - Smoother turn entry and exit
   - Speed optimization through corners
   - Minimal steering corrections post-turn

2. **Adaptive Speed Control:**
   - Variable speed based on track sections
   - Slow for obstacles, fast for straights
   - Smooth acceleration/deceleration curves

3. **Robust Error Recovery:**
   - Detect and recover from localization errors
   - Backup navigation strategies
   - Automatic reset and retry logic

4. **Multi-Strategy System:**
   - Different approaches for different track layouts
   - Automatic strategy selection based on conditions
   - A/B testing framework for strategies

---

# Acknowledgments 

Team Delta K would like to express our gratitude to everyone who supported us throughout this journey:

**Haque Academy**
Thank you to our school for providing facilities, encouragement, and the opportunity to represent Pakistan at the international level. Your support for STEM education and robotics programs has been instrumental in our development.

**Coach Ali Saif**
Thank you for your guidance, patience, and technical expertise. Your mentorship helped us navigate challenges and pushed us to achieve more than we thought possible.

<!-- ⚠️⚠️⚠️ REMINDER: ADD ANY OTHER ACKNOWLEDGMENTS ⚠️⚠️⚠️ -->
<!-- Include: Family members, sponsors, mentors, community support, etc. -->

**[Add additional acknowledgments]:**
- Family members who supported late-night testing sessions
- Any sponsors or donors who provided financial support
- Community members who offered advice or resources
- Online communities (forums, Discord servers) that helped with technical issues

**World Robot Olympiad**
Thank you to WRO Pakistan and WRO International for organizing this incredible competition and providing a platform for young engineers to showcase their skills and learn from peers worldwide.

**Open Source Community**
This project was made possible by countless open-source contributors. We especially thank the developers of:
- OpenCV
- RPLidar Python library
- Raspberry Pi Foundation
- Arduino/MicroPython communities

**National Competition Organizers**
Thank you for providing test mats, traffic signs, and a well-organized competition environment that allowed us to perform at our best.

---

# Resources 

## Documentation Files

All technical documentation, code, and 3D models are available in this repository:

<!-- ⚠️⚠️⚠️ REMINDER: ORGANIZE ALL FILES IN APPROPRIATE FOLDERS ⚠️⚠️⚠️ -->

```
delta-bot-wro2025/
│
├── README.md (this file)
│
├── code/
│   ├── raspberry-pi/         # Python code for Pi 5
│   └── xrp-board/            # MicroPython code for XRP
│
├── 3d-models/                 # STL files for all printed parts
│   ├── chassis/
│   ├── motor-system/
│   ├── steering/
│   ├── sensor-mounts/
│   └── electronics/
│
├── electrical-diagram/        # Circuit diagrams and wiring schematics
│
├── hardware-photos/           # Component and assembly photos
│
├── robot-photos/              # Six-view robot images
│
├── team-photos/               # Team member photos
│
├── testing-videos/            # Performance videos
│
└── documentation/             # Additional technical documents
    ├── calibration-guide.md
    ├── troubleshooting.md
    └── competition-checklist.md
```

## External Resources

**Official WRO Resources:**
- [WRO 2025 Official Rules](https://wro-association.org/competition/season-2025/)
- [Future Engineers Category Guide](https://wro-association.org/)
- [WRO Pakistan National Website](https://wro.org.pk/)

**Component Documentation:**
- [Raspberry Pi 5 Documentation](https://www.raspberrypi.com/documentation/computers/raspberry-pi-5.html)
- [XRP Platform Documentation](https://xrpplatform.org/)
- [RPLidar A2 Documentation](https://www.slamtec.com/en/Lidar/A2)
- [OpenCV Python Tutorials](https://docs.opencv.org/4.x/d6/d00/tutorial_py_root.html)
- [LSM6DSOX IMU Datasheet](https://www.st.com/en/mems-and-sensors/lsm6dsox.html)

**Technical Learning Resources:**
- [Autonomous Navigation Basics](https://en.wikipedia.org/wiki/Autonomous_robot)
- [Computer Vision for Robotics](https://opencv.org/)
- [PID Control Tutorial](https://en.wikipedia.org/wiki/PID_controller)
- [LiDAR SLAM Algorithms](https://en.wikipedia.org/wiki/Simultaneous_localization_and_mapping)

**CAD and 3D Printing:**
- [Fusion 360 (Free for Students)](https://www.autodesk.com/products/fusion-360/students-teachers-educators)
- [Creality K1C User Manual](https://www.creality.com/)
- [3D Printing Best Practices](https://all3dp.com/)

**Community Forums:**
- [Raspberry Pi Forums](https://forums.raspberrypi.com/)
- [WRO Discussion Forums](https://wro-association.org/community/)
- [ROS Robotics Forums](https://discourse.ros.org/)

---

## Project Statistics

**Development Timeline:**
- **Total Development Time:** 6 months
- **Design Iterations:** 4 major versions
- **Code Lines Written:** [Add approximate line count]
- **3D Printed Parts:** 30+ components
- **Testing Hours:** [Add approximate hours]
- **Practice Runs:** [Add number]

**Team Effort:**
- **Total Team Hours:** [Add estimate]
- **Design Meetings:** Weekly sessions
- **Testing Sessions:** 2-3 times per week
- **Documentation Hours:** [Add estimate]

---

# License 

```
MIT License

Copyright (c) 2025 Delta K - Team Pakistan (Kabir, Kosain, Rayyan)

Permission is hereby granted, free of charge, to any person obtaining a copy
of this software and associated documentation files (the "Software"), to deal
in the Software without restriction, including without limitation the rights
to use, copy, modify, merge, publish, distribute, sublicense, and/or sell
copies of the Software, and to permit persons to whom the Software is
furnished to do so, subject to the following conditions:

The above copyright notice and this permission notice shall be included in all
copies or substantial portions of the Software.

THE SOFTWARE IS PROVIDED "AS IS", WITHOUT WARRANTY OF ANY KIND, EXPRESS OR
IMPLIED, INCLUDING BUT NOT LIMITED TO THE WARRANTIES OF MERCHANTABILITY,
FITNESS FOR A PARTICULAR PURPOSE AND NONINFRINGEMENT. IN NO EVENT SHALL THE
AUTHORS OR COPYRIGHT HOLDERS BE LIABLE FOR ANY CLAIM, DAMAGES OR OTHER
LIABILITY, WHETHER IN AN ACTION OF CONTRACT, TORT OR OTHERWISE, ARISING FROM,
OUT OF OR IN CONNECTION WITH THE SOFTWARE OR THE USE OR OTHER DEALINGS IN THE
SOFTWARE.
```

---

## Open Source Commitment

Team Delta K is committed to open-source collaboration and knowledge sharing. All code, CAD files, and documentation in this repository are freely available for:

✅ **Learning and Education:** Study our design decisions and implementation  
✅ **Modification:** Adapt our designs for your own projects  
✅ **Sharing:** Distribute and teach others using our materials  
✅ **Commercial Use:** Use in commercial projects (attribution appreciated)  

**We encourage you to:**
- Fork this repository and build upon our work
- Share improvements and innovations with the community
- Provide feedback and suggestions via GitHub Issues
- Credit Delta K if our work helps your project

**Contributing:**
If you improve upon our design or find bugs, please consider:
1. Opening a GitHub Issue to discuss the changes
2. Submitting a Pull Request with your improvements
3. Documenting your changes clearly

Together, we can advance the state of autonomous robotics education!

---

## Contact Information

<!-- ⚠️⚠️⚠️ REMINDER: ADD TEAM CONTACT INFORMATION ⚠️⚠️⚠️ -->

**Team Delta K**  
Haque Academy, Karachi, Pakistan

**Email:** [Add team email]  
**GitHub:** [Add GitHub organization/repo link]  
**Instagram:** [Add Instagram handle]  
**YouTube:** [Add YouTube channel]  
**Website:** [Add website if available]

**For inquiries about:**
- Technical questions about our robot design
- Collaboration opportunities
- Speaking engagements or presentations
- Media requests

Please reach out via email or open a GitHub issue.

---

## Final Thoughts

Participating in WRO 2025 Future Engineers has been an incredible journey for Team Delta K. From the frustration of Pi 4 camera issues to the panic of melted wires at nationals, from celebrating our first successful autonomous lap to earning 3rd place nationally—every moment taught us invaluable lessons.

**What we learned extends far beyond robotics:**
- **Perseverance:** Four design iterations taught us to embrace failure as learning
- **Teamwork:** Three team members, one shared vision, countless late nights
- **Problem-Solving:** Real engineering means finding creative solutions under pressure
- **Time Management:** Balancing school, robotics, and personal life
- **Documentation:** Sharing knowledge amplifies impact

**To future WRO teams:**

Don't wait for perfect conditions—start building now. Your first robot will be terrible, and that's exactly the point. Each failure reveals what you didn't know you needed to learn. Invest in proper hardware early (yes, that Raspberry Pi 5 is worth it). Document everything, even mistakes. Test relentlessly. And remember: the robot that crosses the finish line is built on the failures of the ones that didn't.

**To our competitors:**

We hope this documentation helps you avoid our mistakes and build upon our successes. Robotics advances fastest when we share openly. May the best robot win—and may we all learn together.

**Our next challenge:**

International competition, here we come! We're already planning improvements: better parking algorithms, smoother turning, and maybe—just maybe—a perfect run.

---

<p align="center">
  <b>Team Delta K - Pakistan</b><br>
  WRO 2025 Future Engineers<br>
  <i>"From Karachi to the World"</i>
</p>

<p align="center">
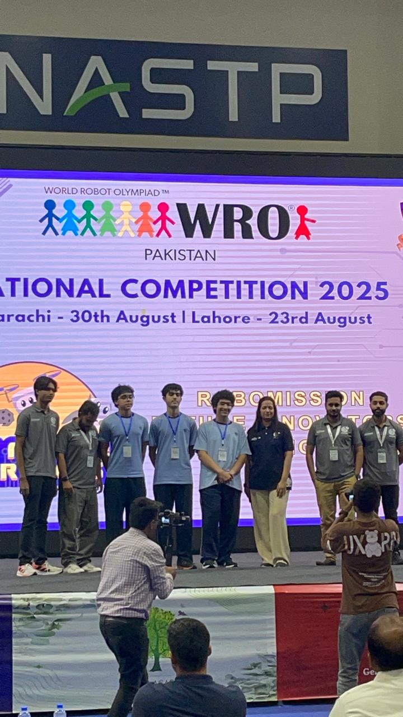
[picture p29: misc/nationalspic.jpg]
Team Delta K Celebrating 3rd Place
  
</p>

---

## Repository Quick Links

**Essential Files:**
- [Main Robot Code (Raspberry Pi)](./code/raspberry-pi/main.py)
- [XRP Controller Code](./code/xrp-board/xrp_main.py)
- [3D Model Files (STL)](./3d-models/)
- [Circuit Diagram](./electrical-diagram/delta-bot-circuit.png)
- [Construction Guide](#robot-construction-guide)
- [Cost Report](#cost-report)

**Documentation:**
- [Calibration Guide](./documentation/calibration-guide.md)
- [Troubleshooting Guide](./documentation/troubleshooting.md)
- [Competition Checklist](./documentation/competition-checklist.md)

**Media:**
- [Robot Photos](./robot-photos/)
- [Performance Videos](./testing-videos/)
- [Team Photos](./team-photos/)

---

## Version History

**v1.0.0** - January 2025
- Initial release for WRO 2025 International Competition
- Complete documentation of Delta Bot design
- All code, CAD files, and technical specifications included
- National competition 3rd place configuration

**v0.4.0** - December 2024  
- Fourth iteration (competition version)
- Raspberry Pi 5 integration
- Complete LiDAR mapping system
- Obstacle avoidance refined

**v0.3.0** - November 2024
- Third iteration
- Switched to Raspberry Pi 5
- Resolved camera and LiDAR processing issues

**v0.2.0** - October 2024
- Second iteration with Raspberry Pi 4
- LiDAR integration attempted
- Camera communication issues identified

**v0.1.0** - September 2024
- First iteration with Arduino Uno
- Basic ultrasonic navigation
- Identified need for better processing power

---

## Changelog

**Future Updates:**
- [ ] Add parking challenge improvements
- [ ] Optimize turning algorithms
- [ ] Add machine learning obstacle detection
- [ ] Create video tutorials for construction
- [ ] Add simulation environment setup guide
- [ ] Publish competition performance analysis

---

## FAQ

**Q: Can I use this design for my WRO team?**  
A: Absolutely! That's why we made it open source. Feel free to use, modify, and improve upon our design.

**Q: What's the minimum budget to replicate this robot?**  
A: Approximately 1,300 CAD (~$950 USD) for all components, excluding tools. See [Cost Report](#cost-report) for details.

**Q: Why Raspberry Pi 5 instead of Arduino or Pi 4?**  
A: We tried both! Arduino lacks camera support and processing power. Pi 4 couldn't handle LiDAR data in real-time. Pi 5's quad-core 2.4GHz processor was essential for our multi-sensor approach.

**Q: How long did it take to build?**  
A: Six months from first concept to national competition, including four major design iterations.

**Q: What's the hardest part of this project?**  
A: Sensor fusion—combining LiDAR, camera, IMU, and encoder data into coherent decisions. Also, the parking challenge (still working on it!).

**Q: Can this robot work outdoors?**  
A: Not reliably. Camera color detection is very sensitive to lighting. It's optimized for indoor competition lighting.

**Q: What programming experience is needed?**  
A: Intermediate Python (OpenCV, NumPy, object-oriented programming) and basic MicroPython. Our code is well-commented to help learners.

**Q: Why not use ROS (Robot Operating System)?**  
A: ROS is powerful but adds complexity. For WRO's focused tasks, our custom Python architecture was simpler and more performant.

**Q: How can I contribute to this project?**  
A: Fork the repository, make improvements, and submit pull requests! We especially welcome parking challenge improvements and code optimizations.

**Q: Where can I buy the components in Pakistan?**  
A: Most electronics are available from local suppliers in Karachi or online through Daraz.pk. Some specialized items (RPLidar, Raspberry Pi 5) may need to be imported.

---

<p align="center">
  ⭐ If this documentation helped you, please give us a star on GitHub! ⭐
</p>

<p align="center">
  <i>Built with passion in Karachi 🇵🇰 | Competing for the world 🌍</i>
</p>

---

**Last Updated:** January 2025  
**Repository:** github.com/[your-username]/delta-bot-wro2025  
**Competition:** WRO 2025 Future Engineers International  
**Team:** Delta K - Kabir, Kosain, Rayyan  
**Coach:** Ali Saif  
**School:** Haque Academy, Karachi, Pakistan

---

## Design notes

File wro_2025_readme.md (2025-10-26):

<center><h1> Delta K - WRO 2025 Future Engineers </h1></center>

<!-- ⚠️⚠️⚠️ REMINDER: ADD TEAM BANNER IMAGE HERE ⚠️⚠️⚠️ -->
Banner


<!-- ⚠️⚠️⚠️ REMINDER: ADD SOCIAL MEDIA LINKS (Instagram, YouTube, etc.) ⚠️⚠️⚠️ -->



This repository contains the complete documentation for Team Delta K's autonomous robot for the 2025 World Robot Olympiad Future Engineers competition. Delta Bot was designed, built, and programmed by three dedicated students from Karachi, Pakistan, representing Haque Academy on the international stage.

## Table of Contents
* [The Team](#team)
* [The Challenge](#challenge)
* [The Robot](#robot-image)
* [Performance Video](#video)
* [Development Journey](#development-journey)
* [Mobility Management](#mobility-management)
  * [Custom Motor Design](#custom-motor-design)
  * [Steering System](#steering-system)
  * [Drivetrain](#drivetrain)
  * [Chassis](#chassis)
  * [Wheels](#wheels)
* [Power and Sense Management](#power-and-sense-management)
  * [Raspberry Pi 5](#raspberry-pi-5)
  * [XRP Controller Board](#xrp-board)
  * [Vision System - PiCam2](#picam2)
  * [RPLidar A2M12](#rplidar)
  * [LSM6DSOX IMU](#imu-sensor)
  * [HC-SR04 Ultrasonic Sensor](#ultrasonic)
  * [Motor Encoder](#motor-encoder)
  * [Power System](#power-system)
  * [Circuit Diagram](#circuit-diagram)
* [Software Architecture](#software-architecture)
  * [Code Structure](#code-structure)
  * [Computer Vision](#computer-vision)
  * [Sensor Fusion](#sensor-fusion)
  * [Communication Protocol](#communication)
* [Obstacle Management](#obstacle-management)
  * [Qualification Round Strategy](#quali-strategy)
  * [Obstacle Round Strategy](#obstacle-strategy)
  * [Parking Challenge](#parking-challenge)
* [Code Implementation](#code-implementation)
  * [Main Control Loop](#main-loop)
  * [LiDAR Mapping](#lidar-code)
  * [Color Detection](#color-detection-code)
  * [IMU Integration](#imu-code)
  * [Motor Control](#motor-control-code)
  * [Obstacle Avoidance](#obstacle-avoidance-code)
* [Robot Construction Guide](#robot-construction-guide)
* [Cost Report](#cost-report)
* [Testing & Results](#testing-results)
* [Future Improvements](#future-improvements)
* [Acknowledgments](#acknowledgments)
* [Resources](#resources)
* [License](#license)

---

## The Team 

<!-- ⚠️⚠️⚠️ REMINDER: ADD ALL TEAM MEMBER PHOTOS IN ./team-photos/ FOLDER ⚠️⚠️⚠️ -->

### Kabir - Project Manager & Documentation Lead
<p align="center">
  Kabir
</p>

**Age:** 15

**School:** Haque Academy, Karachi, Pakistan

**Role:** Project Manager & Documentation Lead

**Description:** Hi! I'm Kabir, and I'm passionate about programming, public speaking, leadership, and staying fit through gymming. WRO 2025 represents an incredibly interesting challenge and a golden opportunity to showcase our robotics skills on the international stage. My strengths lie in organizing the team, maintaining comprehensive documentation, managing our GitHub repository, and planning the robot's development roadmap. I previously qualified at the national level for the International Robot Olympiad (IRO) in Greece, which gave me valuable competition experience. What I enjoy most about my role is seeing our robot's progress grow in real-time—watching our ideas transform from sketches to a fully functional autonomous vehicle is incredibly rewarding. Leading this team and documenting every step of our journey has taught me that success comes from meticulous planning, clear communication, and relentless dedication to improvement.

---

### Kosain - Lead Programmer
<p align="center">
  Kosain
</p>

**Age:** 16

**School:** Haque Academy, Karachi, Pakistan

**Role:** Lead Programmer

**Description:** Hello! I'm Kosain, the lead programmer for Team Delta K. I've been fascinated by programming since I was 6 or 7 years old—what drew me in was how extremely logical it is, and my school provided many opportunities to learn and grow. Over the years, I've become proficient in Python, C, C++, C#, HTML, CSS, and JavaScript. I've worked on diverse projects including wireless remote control protocols, AI frontend development, image editor software built on ESP32, an electronic dice, a formula calculator, and even a malware debunker tool. What I love most about programming is its pure logic—every problem has a solution if you think systematically. Beyond software, I have a strong interest in the hardware side of things, which is why robotics is the perfect blend of my passions. For this competition, I'm handling all the computer vision, sensor integration, and control algorithms that bring Delta Bot to life. The challenge of making real-time decisions based on multiple sensor inputs is exactly the kind of complex problem I thrive on solving.

---

### Rayyan - Lead Hardware & Construction
<p align="center">
  Rayyan
</p>

**Age:** 15

**School:** Haque Academy, Karachi, Pakistan

**Role:** Lead Hardware & Construction

<!-- ⚠️⚠️⚠️ REMINDER: ADD RAYYAN'S DETAILED DESCRIPTION ⚠️⚠️⚠️ -->
<!-- Include: His building experience, mechanical interests, problem-solving approach, previous projects, hobbies outside robotics -->
**Description:** [Add Rayyan's personal description here - discuss his hands-on experience with 3D printing, CAD design, mechanical assembly, what mechanical concepts fascinate him (gears, linkages, structural integrity), how he approaches debugging hardware issues, any previous building projects, and his interests outside of robotics like sports or other hobbies]

---

### Ali Saif - Coach
<p align="center">
  Ali Saif
</p>

**Role:** Team Coach

<!-- ⚠️⚠️⚠️ REMINDER: ADD COACH ALI SAIF'S DETAILED DESCRIPTION ⚠️⚠️⚠️ -->
<!-- Include: His background/expertise, teaching experience, coaching philosophy, technical expertise, previous coaching success, what he emphasizes most -->
**Description:** [Add Ali Saif's background - his educational/professional background, how long he's been coaching robotics/STEM, his coaching philosophy (hands-on learning, fostering student independence, strategic thinking), specific technical expertise he brings (programming, electronics, mechanical design), any previous successful teams he's coached, and what he emphasizes most when mentoring the team]

---

### Team Photo
<p align="center">
  Team Delta K
</p>

<!-- ⚠️⚠️⚠️ REMINDER: ADD TEAM FORMATION STORY & DYNAMICS ⚠️⚠️⚠️ -->
<!-- Include: How the team formed, how you knew each other, why you decided to work together, team dynamic, how you divide work, resolve disagreements, memorable moments during development -->

**Team Formation:** [Describe how Delta K was formed, how team members knew each other beforehand, what brought you together for WRO, and what makes your team dynamic special]

**Team Dynamic:** [Explain how you work together, divide responsibilities, handle disagreements, celebrate successes, and any funny or memorable moments during the 6-month development process]

---

## The Challenge 

The **[WRO 2025 Future Engineers - Self-Driving Cars](https://wro-association.org/)** challenge represents the pinnacle of student robotics competitions, inviting teams worldwide to design, build, and program fully autonomous vehicles. The competition simulates real-world self-driving car scenarios with three distinct challenges:

**1. Open Challenge (Qualification Round):** Robots must autonomously navigate a track with randomly placed walls, completing three laps in the fastest time possible. The direction of travel (clockwise or counterclockwise) is determined by detecting colored lines (orange or blue) at the track's corners.

**2. Obstacle Challenge (Final Round):** Building on the qualification round, robots must now avoid randomly placed traffic signs (red and green pillars) while maintaining speed and efficiency. The challenge includes a mandatory U-turn rule: if the last obstacle in the second lap is red, the robot must turn around and complete the final lap in the opposite direction.

**3. Parking Challenge:** After completing the obstacle rounds, robots must identify a parking space marked by magenta walls and execute a precise parallel parking maneuver.

**Key Technical Requirements:**
- **Mobility Management:** Efficient motor control, precise steering, and robust mechanical design
- **Sensor Fusion:** Integration of multiple sensors (camera, LiDAR, IMU, encoders) for environmental awareness
- **Computer Vision:** Real-time color detection and object recognition for obstacles and parking spaces
- **Path Planning:** Dynamic navigation using sensor data to avoid collisions and optimize routes
- **Documentation:** Comprehensive engineering documentation in a public GitHub repository demonstrating the entire development process

**Scoring Criteria:**
- Performance in competition rounds (speed, accuracy, obstacle avoidance)
- Quality and completeness of engineering documentation
- Innovation in design and problem-solving approaches
- Team presentation and ability to explain technical decisions

This challenge emphasizes the complete engineering process—from conceptual design through iterative prototyping, testing, and final implementation. It pushes teams to integrate mechanical engineering, electronics, computer science, and project management skills while fostering creativity, teamwork, and resilience in the face of technical challenges.

Learn more about the WRO 2025 challenge rules and specifications [here](https://wro-association.org/competition/season-2025/).

---

## Photos of Our Robot: Delta Bot 

<!-- ⚠️⚠️⚠️ REMINDER: ADD ALL SIX ROBOT PHOTOS (front, back, left, right, top, bottom) IN ./robot-photos/ FOLDER ⚠️⚠️⚠️ -->

Delta Bot represents our team's sixth month of intensive engineering, combining cutting-edge sensors with custom mechanical solutions. Powered by a Raspberry Pi 5 and equipped with RPLidar for 360-degree environmental mapping, Delta Bot achieves autonomous navigation through advanced sensor fusion and real-time path planning.

| Front View | Back View | 
| :--: | :--: |
|  |  |
| **Left View** | **Right View** |
|  |  |
| **Top View** | **Bottom View** |
|  |  |

<!-- ⚠️⚠️⚠️ REMINDER: ADD ROBOT SPECIFICATIONS TABLE ⚠️⚠️⚠️ -->
<!-- ⚠️⚠️⚠️ REMINDER: MEASURE AND ADD ROBOT WEIGHT ⚠️⚠️⚠️ -->
<!-- ⚠️⚠️⚠️ REMINDER: MEASURE AND ADD ROBOT DIMENSIONS (Length x Width x Height) ⚠️⚠️⚠️ -->

**Key Specifications:**
- **Dimensions:** [Length] cm x [Width] cm x [Height] cm
- **Weight:** [X] grams
- **Brain:** Raspberry Pi 5 (8-core CPU, 8GB RAM)
- **Vision:** PiCam2 with OpenCV processing
- **Mapping:** RPLidar A2M12 (360° scanning, 12m range)
- **Navigation:** LSM6DSOX IMU (6-axis gyroscope + accelerometer)
- **Drive System:** Custom dual-axle motor with DG01D-E encoder
- **Steering:** SG90 micro servo with parallel linkage mechanism
- **Power:** 3x 1500mAh LiPo batteries with voltage regulation
- **Construction:** 30+ 3D printed PLA+ components

---

## Our Performance Video 

<!-- ⚠️⚠️⚠️ REMINDER: UPLOAD COMPETITION/TESTING VIDEO TO YOUTUBE AND ADD LINK HERE ⚠️⚠️⚠️ -->

Watch Delta Bot in action:

[Youtube video link to be added]

**Competition Performance Highlights:**
- **Qualification Round Best Time:** 14 seconds
- **Obstacle Round Score:** 10.0 (14 points)
- **National Competition Result:** 3rd Place (Qualified for International Competition)

---

## Development Journey 

Delta Bot's development spanned six months and four major design iterations, each addressing critical challenges and pushing our capabilities further.

### **Iteration 1: The Arduino Attempt (Month 1)**
Our first design used an Arduino Uno as the main controller with basic ultrasonic sensors for navigation. We quickly discovered the Arduino's limitations:
- **Camera compatibility** was extremely unstable and unreliable
- **Color sensors** proved inadequate for the obstacle challenge—they couldn't reliably distinguish between red and green traffic signs
- **Processing power** was insufficient for real-time decision-making

**Lesson Learned:** Budget hardware severely limits autonomous capabilities. Vision and processing power are non-negotiable for competition-level performance.

### **Iteration 2: Raspberry Pi 4 with Ambition (Months 2-3)**
We upgraded to a Raspberry Pi 4, expecting significant improvements. Instead, we encountered our biggest setback:
- **Camera communication** took nearly a month to debug—the Pi 4 struggled with consistent PiCam integration
- **LiDAR data overload**—the RPLidar A2M12 generates massive amounts of data, completely overwhelming the Pi 4's processing capabilities
- The robot would freeze or make delayed decisions, making it completely uncompetitive

**Breakthrough Moment:** We realized we needed significantly more processing power, not just incremental upgrades.

### **Iteration 3: The Raspberry Pi 5 Revolution (Month 4)**
Switching to the Raspberry Pi 5 transformed our project:
- **8-core processor** effortlessly handled LiDAR data, camera processing, and navigation algorithms simultaneously
- **Improved camera support** eliminated communication issues entirely
- **Real-time performance** finally achieved—Delta Bot could process sensor data and react within milliseconds

This upgrade was expensive but absolutely critical to our success.

### **Iteration 4: Mechanical Refinement & Custom Motor (Months 5-6)**
With electronics stable, we focused on mechanical optimization:
- **Custom motor design:** We disassembled TT motor bodies and integrated DG01D-E encoders, creating a dual-axle system where the motor sits between both rear wheels
- **30+ 3D printed parts:** Designed and refined chassis, motor mounts, sensor holders, and linkages
- **Weight optimization:** Iterative printing reduced unnecessary material while maintaining structural integrity
- **Parallel linkage steering:** Achieved reliable, precise steering without complex Ackermann geometry

### **Crisis at Nationals**
Just before the obstacle round at WRO Pakistan Nationals, disaster struck: ultrasonic sensor wiring short-circuited, melting the wires. With only minutes before our run, the team had to:
1. Quickly strip and reconnect all ultrasonic sensor wiring
2. Test functionality without time for proper debugging
3. Compete with hastily repaired electronics

Despite this setback, Delta Bot placed **3rd nationally** and qualified for the **international competition**—a testament to the robot's robust design and the team's ability to perform under extreme pressure.

### **Key Takeaways:**
- **Start with sufficient processing power**—upgrading mid-project wastes time
- **Plan for redundancy**—backup sensors and modular wiring saved us at nationals
- **Document everything**—clear documentation allowed rapid troubleshooting
- **Iterate relentlessly**—each failure taught us what really matters in autonomous robotics

---

# Mobility Management 

Delta Bot's mobility system is the result of extensive iteration and custom engineering. After testing multiple motor configurations and steering mechanisms, we developed a unique dual-axle drivetrain that maximizes encoder precision while maintaining a compact footprint.

## Custom Motor Design 

<!-- ⚠️⚠️⚠️ REMINDER: ADD IMAGES OF CUSTOM MOTOR ASSEMBLY ⚠️⚠️⚠️ -->
<!-- Include: Disassembled motor photos, encoder integration photos, dual-axle configuration photos -->
<p align="center">
  Custom Motor Assembly
</p>

### Design Philosophy

Off-the-shelf motors with encoders couldn't meet our specific requirement: the motor needed to physically sit **between** the two rear wheels, with the axle passing through both sides. This configuration was essential for:
- **Balanced weight distribution** across the rear axle
- **Direct mechanical connection** to both wheels without complex differential systems
- **Precise encoder feedback** for accurate distance measurement
- **Compact chassis design** by centralizing the motor

### Custom Modifications

Starting with a **TT Motor Yellow Geared DC Motor body**, we performed the following modifications:

1. **Motor Disassembly:** Carefully disassembled the motor casing to access the internal shaft
2. **Encoder Integration:** Integrated the **DG01D-E Motor Encoder** directly onto the motor shaft for absolute position tracking
3. **Dual-Axle Slots:** Machined slots on both sides of the motor housing to allow the axle to pass completely through
4. **Reassembly with Precision:** Reassembled the motor with the encoder securely mounted, ensuring no mechanical play

<!-- ⚠️⚠️⚠️ REMINDER: ADD 3D MODEL/BLUEPRINT OF CUSTOM MOTOR MOUNTING SYSTEM ⚠️⚠️⚠️ -->

**Technical Specifications:**
- **Base Motor:** TT Motor Yellow Geared DC Motor
- **Encoder:** DG01D-E (quadrature encoder for precise position feedback)
- **Gear Ratio:** [Add gear ratio]
- **Operating Voltage:** 6-12V
- **Configuration:** Dual-axle pass-through design
- **Mounting:** Custom 3D printed motor mounts

### Why This Matters

The custom motor design eliminates the need for a differential while providing:
- **Encoder precision:** Real-time wheel position feedback accurate to fractions of a degree
- **Direct drive efficiency:** No power loss through gears or belts
- **Simplified control:** Both rear wheels are mechanically locked together, simplifying motor control algorithms
- **Compact footprint:** The motor doesn't protrude from the chassis, reducing overall robot size

<!-- ⚠️⚠️⚠️ REMINDER: ADD 3D PRINTED MOTOR MOUNT BLUEPRINTS ⚠️⚠️⚠️ -->

---

## Steering System 

<!-- ⚠️⚠️⚠️ REMINDER: ADD STEERING MECHANISM PHOTOS AND DIAGRAMS ⚠️⚠️⚠️ -->
<p align="center">
  Steering System
</p>

### Parallel Linkage Design

After experimenting with Ackermann steering and direct servo-to-wheel connections, we settled on a **parallel linkage mechanism** for its simplicity, reliability, and sufficient turning radius.

**Key Components:**
- **SG90 9g Micro Servo Motor**
  - Torque: 1.8 kg·cm (4.8V)
  - Speed: 0.1 sec/60° (4.8V)
  - Rotation: 180° (sufficient for full left/right steering)
  - Weight: 9g (minimal impact on front-end weight distribution)

- **3D Printed Linkages:** Connect the servo horn to both front wheel holders, ensuring synchronized steering
- **Wheel Holders:** Custom-designed to allow smooth rotation while maintaining structural rigidity

### Steering Geometry

The parallel linkage geometry provides:
- **Turning Radius:** Approximately [X] cm (suitable for WRO track dimensions)
- **Steering Angle:** ±[X]° from center
- **Response Time:** <100ms from command to full deflection

While not true Ackermann steering (which would provide optimal tire scrub reduction), our testing showed that for Delta Bot's weight and speed, the parallel linkage performs adequately without significant tire wear or turning inefficiency.

<!-- ⚠️⚠️⚠️ REMINDER: ADD 3D BLUEPRINTS OF STEERING LINKAGES AND WHEEL HOLDERS ⚠️⚠️⚠️ -->

**Potential Improvements:**
- Implement Ackermann geometry for competition at higher speeds
- Use ball-bearing joints instead of printed pivots to reduce friction
- Upgrade to a digital servo for finer angle control

---

## Drivetrain 

<!-- ⚠️⚠️⚠️ REMINDER: ADD DRIVETRAIN ASSEMBLY PHOTOS ⚠️⚠️⚠️ -->

### Rear Axle Configuration

The rear axle is the mechanical heart of Delta Bot, directly connecting both rear wheels through the custom motor assembly.

**Axle Design:**
- **Material:** [Specify material - steel rod, aluminum, 3D printed composite?]
- **Diameter:** [Specify diameter in mm]
- **Length:** Spans the full width of the chassis, passing through the motor housing
- **Bearings:** 3D printed bearing holders on each side maintain axle alignment

**Power Transmission:**
1. Motor shaft directly drives the central axle
2. Axle rotates both rear wheels simultaneously (locked differential effect)
3. Encoder tracks axle rotation for precise odometry

### Motor Control

The custom motor is controlled via the **XRP Controller Board**, which features:
- H-bridge motor driver for bidirectional control
- PWM speed control (0-100% duty cycle)
- Current sensing for stall detection
- Integration with Raspberry Pi 5 via serial communication

<!-- ⚠️⚠️⚠️ REMINDER: ADD 3D BLUEPRINTS OF AXLE HOLDERS AND BEARING MOUNTS ⚠️⚠️⚠️ -->

---

## Chassis 

<!-- ⚠️⚠️⚠️ REMINDER: ADD CHASSIS PHOTOS (top view, bottom view, exploded view if available) ⚠️⚠️⚠️ -->
<p align="center">
  Chassis Top View
</p>

### Design Evolution

Delta Bot's chassis underwent four major iterations before reaching its final form. Our design priorities were:
1. **Lightweight construction** to maximize speed and battery life
2. **Sensor accessibility** for easy debugging and adjustment
3. **Modular design** allowing component swaps without full disassembly
4. **Structural rigidity** to prevent flex during high-speed turns

### 3D Printed Architecture

The chassis consists of **30+ custom 3D printed PLA+ components**, including:

**Main Structural Components:**
- Base chassis plate (main structural member)
- Motor mounting brackets (secure custom motor)
- Front axle holders (support steering mechanism)
- Rear axle bearing holders (maintain alignment)

**Sensor Mounting:**
- RPLidar mounting tower (elevated for 360° visibility)
- PiCam2 mount (angled for optimal field of view)
- Ultrasonic sensor brackets (front-facing backup sensor)
- IMU mounting plate (vibration-isolated for accurate readings)

**Electronics Housing:**
- Raspberry Pi 5 mounting tray
- XRP board mounting brackets
- Battery compartment (secures three LiPo batteries)
- Voltage regulator housing

**Cable Management:**
- Wire routing channels integrated into chassis
- Snap-fit cable clips
- Modular connector access ports

### 3D Printing Specifications

- **Printer:** Creality K1C
- **Material:** PLA+ filament (higher strength than standard PLA)
- **Filament Dryer:** Creality Filament Dryer (prevents moisture absorption for consistent prints)
- **Layer Height:** 0.2mm (balance between strength and print time)
- **Infill:** 20% (sufficient strength without excessive weight)
- **Print Time:** Approximately [X] hours total for all components

<!-- ⚠️⚠️⚠️ REMINDER: ADD ALL 3D MODEL BLUEPRINTS/STL FILES IN ./3d-models/ FOLDER ⚠️⚠️⚠️ -->
<!-- Include: Chassis base, motor mounts, sensor mounts, axle holders, electronics trays, cable management clips -->

**Design Files:**
All 3D models are available in the `./3d-models/` directory in STL format, ready for printing.

---

## Wheels 

<!-- ⚠️⚠️⚠️ REMINDER: ADD WHEEL PHOTOS AND TREAD PATTERN CLOSE-UPS ⚠️⚠️⚠️ -->
<p align="center">
  Delta Bot Wheels
</p>

**Specifications:**
- **Type:** 65mm Circular Tracked Treaded Wheels
- **Diameter:** 65mm
- **Tread Pattern:** Deep treads for maximum grip on competition mat
- **Material:** Rubber compound
- **Configuration:** 4-wheel drive (2 powered rear wheels, 2 steered front wheels)

**Performance Characteristics:**
- **Grip:** Excellent traction on the foam mat surface used in WRO competitions
- **Rolling Resistance:** Low enough for efficient battery use
- **Durability:** Treaded design resists wear during testing and competition

The 65mm diameter was chosen to balance:
- **Speed:** Larger diameter = higher top speed at same RPM
- **Torque:** Not so large that motor torque becomes insufficient for acceleration
- **Ground Clearance:** Adequate clearance to avoid scraping on uneven mat sections

---

# Power and Sense Management 

Delta Bot's sensor suite represents a comprehensive approach to environmental awareness, combining vision, mapping, inertial measurement, and proximity sensing for robust autonomous navigation.

## Raspberry Pi 5 

<!-- ⚠️⚠️⚠️ REMINDER: ADD RASPBERRY PI 5 INSTALLATION PHOTO ⚠️⚠️⚠️ -->
<p align="center">
  Raspberry Pi 5
</p>

The **Raspberry Pi 5** serves as Delta Bot's main brain, handling all high-level processing tasks.

**Technical Specifications:**
- **Processor:** Broadcom BCM2712 (Quad-core Cortex-A76 @ 2.4GHz)
- **RAM:** 8GB LPDDR4X
- **Storage:** 256GB NVMe SSD (via PCIe interface) - Cost: 46 CAD
- **GPIO:** 40-pin header for sensor and actuator connections
- **USB:** USB 3.0 ports for camera and LiDAR connectivity
- **Power:** 5V/5A via USB-C (delivered through voltage regulation system)

**Why Raspberry Pi 5?**

After struggling with Arduino Uno (insufficient processing power and poor camera support) and Raspberry Pi 4 (overwhelmed by LiDAR data), the Pi 5 was essential:

1. **Massive Processing Power:** The 2.4GHz quad-core processor handles:
   - Real-time LiDAR data processing (thousands of distance measurements per second)
   - Computer vision algorithms (OpenCV) for color detection and object recognition
   - Sensor fusion algorithms combining IMU, encoder, ultrasonic, and vision data
   - Path planning and navigation decision-making
   
2. **Camera Support:** Native support for PiCam2 with no communication issues

3. **Multi-threading:** Runs separate processes for sensor data acquisition, vision processing, and motor control without lag

4. **NVMe Storage:** Fast SSD storage allows quick boot times and efficient data logging

**Cost:** 140 CAD

---

## XRP Controller Board 

<!-- ⚠️⚠️⚠️ REMINDER: ADD XRP BOARD PHOTO AND CONNECTION DIAGRAM ⚠️⚠️⚠️ -->
<p align="center">
  XRP Controller Board
</p>

The **XRP (Experiential Robotics Platform) Controller Board** serves as the motor control and sensor interface subsystem.

**Key Features:**
- **Built-in Raspberry Pi Pico (RP2040):** Dedicated microcontroller for real-time motor control
- **Integrated LSM6DSOX IMU:** 6-axis gyroscope and accelerometer (included with board)
- **H-Bridge Motor Drivers:** Direct motor control without external drivers
- **Servo Control Pins:** Native support for servo motors
- **Encoder Inputs:** Dedicated pins for quadrature encoder reading
- **GPIO Expansion:** Additional pins for ultrasonic and other sensors

**Communication with Raspberry Pi 5:**
The XRP board communicates with the Raspberry Pi 5 via **serial UART** connection, allowing:
- High-level navigation commands from Pi 5
- Low-level motor control execution on XRP
- Real-time IMU data streaming to Pi 5
- Encoder position feedback for odometry

**Cost:** 60 CAD (includes LSM6DSOX IMU)

---

## Vision System - PiCam2 

<!-- ⚠️⚠️⚠️ REMINDER: ADD CAMERA MOUNTING PHOTO AND FIELD OF VIEW DIAGRAM ⚠️⚠️⚠️ -->
<p align="center">
  PiCam2 Mounted on Delta Bot
</p>

**Specifications:**
- **Sensor:** Sony IMX219 (8-megapixel sensor)
- **Resolution:** 3280 × 2464 pixels (still), 1920 × 1080 @ 30fps (video)
- **Field of View:** 62.2° × 48.8°
- **Interface:** CSI (Camera Serial Interface) direct to Raspberry Pi 5
- **Focus:** Fixed focus optimized for 1-2 meter range

**Mounting Position:**
The camera is mounted at the front of the chassis, angled slightly downward (approximately 15-20°) to capture:
- **Turn lines** (orange and blue) on the track surface
- **Traffic signs** (red and green pillars) at 1-2 meters distance
- **Parking walls** (magenta markers)

**Vision Processing:**
The Pi 5 runs **OpenCV** (Python) for real-time image processing:
- **Color detection** using HSV color space (more robust than RGB under varying lighting)
- **Bounding box creation** around detected objects (obstacles, parking walls)
- **Centroid calculation** for determining object position and distance
- **Real-time frame processing** at 30 fps for responsive obstacle avoidance

**Cost:** 33 CAD

---

## RPLidar A2M12 

<!-- ⚠️⚠️⚠️ REMINDER: ADD RPLIDAR MOUNTING PHOTO AND SCANNING VISUALIZATION ⚠️⚠️⚠️ -->
<p align="center">
  RPLidar A2M12 on Delta Bot
</p>

The **RPLidar A2M12** is Delta Bot's primary navigation sensor, providing 360-degree environmental mapping.

**Technical Specifications:**
- **Range:** 0.15m - 12m
- **Scan Rate:** 5.5Hz - 10Hz (adjustable)
- **Angular Resolution:** 0.9° (400 samples per 360° scan)
- **Sample Rate:** 4000 samples/second
- **Interface:** USB connection to Raspberry Pi 5
- **Power:** 5V/2A
- **Weight:** ~190g (including motor and mounting bracket)

**Mounting Position:**
The LiDAR is mounted on an elevated tower at the center of the robot to ensure:
- **Unobstructed 360° view** (no chassis components block the laser)
- **Correct height** to detect obstacles and walls without floor interference
- **Stability** during high-speed maneuvers (no vibration-induced noise)

**Role in Navigation Strategy:**

1. **Wall Mapping:** Creates a real-time 2D map of the track walls, allowing the robot to understand the track boundaries

2. **Path Planning:** Identifies available space for navigation:
   - Detects gaps in walls for turn detection
   - Calculates safe distances from obstacles
   - Determines parking space location and dimensions

3. **Collision Prevention:** Continuously monitors all directions, preventing collisions with:
   - Track walls
   - Traffic sign obstacles
   - Other unexpected objects

4. **Distance Measurement:** Provides precise distance readings in all directions, used for:
   - Maintaining safe distance from walls during straight-line navigation
   - Measuring distance to obstacles before avoidance maneuvers
   - Confirming parking space dimensions

**Data Processing:**
The LiDAR generates approximately **4000 distance measurements per second**. The Raspberry Pi 5 processes this data stream to:
- Filter noise and outliers
- Build occupancy grid maps
- Identify clusters (walls, obstacles)
- Calculate free space for path planning

**Why LiDAR was Essential:**
Our early ultrasonic-only approach failed because:
- Ultrasonic sensors have narrow fields of view (~15°)
- Multiple ultrasonics cause interference
- Cannot create comprehensive maps

The LiDAR provides complete environmental awareness that ultrasonics simply cannot match.

**Cost:** 210 CAD

---

## LSM6DSOX IMU 

<!-- ⚠️⚠️⚠️ REMINDER: ADD IMU MOUNTING PHOTO ⚠️⚠️⚠️ -->
<p align="center">
  LSM6DSOX IMU
</p>

**Technical Specifications:**
- **Chip:** STMicroelectronics LSM6DSOX
- **Gyroscope Range:** ±125/±250/±500/±1000/±2000 dps (degrees per second)
- **Accelerometer Range:** ±2/±4/±8/±16 g
- **Interface:** I2C (integrated into XRP board)
- **Update Rate:** Up to 6.66 kHz (configurable)
- **Precision:** 16-bit ADC resolution

**Integrated with XRP Board:**
The LSM6DSOX comes pre-soldered and integrated with the XRP Controller Board, eliminating the need for separate wiring and mounting.

**Role in Navigation:**

The IMU is critical for **precise turning and orientation tracking**:

1. **Gyroscope (Primary Use):** Measures angular velocity (rotation rate) around the Z-axis (vertical axis of the robot). By integrating angular velocity over time, we calculate the robot's current heading angle.

2. **Turn Angle Calculation:** 
   - Robot starts at 0° heading
   - IMU integrates gyroscope data to track cumulative angle change
   - When turning 90° at corners, IMU ensures exact 90° rotation (not 87° or 93°)
   - Critical for maintaining orientation after multiple turns

3. **Drift Compensation:** 
   - All IMUs experience drift (small errors accumulate over time)
   - We calibrate drift during initialization
   - Periodic corrections using LiDAR wall alignment prevent long-term drift

4. **Accelerometer (Secondary Use):**
   - Detects sudden impacts or collisions
   - Monitors robot tilt (ensures robot is level)
   - Validates motion (confirms robot is actually moving when motors are commanded)

**Why IMU was Essential:**
Early attempts using only encoder-based dead reckoning for turns resulted in:
- Cumulative angle errors (small steering imperfections compound)
- Wheel slip causing angle miscalculations
- Inability to recover from collisions or unexpected pushes

The IMU provides **absolute angular velocity measurement** independent of wheel motion, ensuring turns are always precise.

**Cost:** Included with XRP Board (60 CAD total)

---

## HC-SR04 Ultrasonic Sensor 

<!-- ⚠️⚠️⚠️ REMINDER: ADD ULTRASONIC SENSOR MOUNTING PHOTO ⚠️⚠️⚠️ -->
<p align="center">
  HC-SR04 Ultrasonic Sensor
</p>

**Technical Specifications:**
- **Operating Voltage:** 5V
- **Range:** 2cm - 400cm
- **Accuracy:** ±3mm
- **Measuring Angle:** 15° cone
- **Trigger Pulse:** 10µs
- **Echo Pulse:** Proportional to distance

**Mounting Position:**
Front-facing, centered on the chassis

**Role in System:**
The ultrasonic sensor serves as a **backup/redundancy sensor** to the LiDAR:

1. **Front Obstacle Detection:** Quickly detects objects directly in front
2. **LiDAR Validation:** Cross-checks LiDAR readings for critical front obstacles
3. **Close-Range Safety:** Ultrasonic performs better than LiDAR at very close range (<15cm)
4. **Emergency Stop:** Can trigger emergency braking if front obstacle is too close

**Why Backup Sensor?**
During nationals, when our ultrasonic wiring short-circuited, the robot could still function using LiDAR alone. However, the ultrasonic provides:
- Faster response time for front obstacles (simpler processing than LiDAR)
- Redundancy in case of LiDAR failure
- Confidence in front-facing decisions

**Cost:** 14 CAD

---

## Motor Encoder 

<!-- ⚠️⚠️⚠️ REMINDER: ADD ENCODER INTEGRATION PHOTO ⚠️⚠️⚠️ -->

**Specifications:**
- **Type:** DG01D-E Quadrature Encoder
- **Resolution:** [Specify pulses per revolution]
- **Output:** Two-channel quadrature signal (A and B phases)
- **Interface:** Connected to XRP board encoder inputs

**Integration:**
The encoder is integrated directly into our custom motor assembly (see [Custom Motor Design](#custom-motor-design)), providing precise feedback on wheel rotation.

**Role in Odometry:**

1. **Distance Measurement:** By counting encoder pulses and knowing wheel diameter, we calculate exact distance traveled:
   ```
   Distance = (Encoder Pulses / Pulses per Revolution) × Wheel Circumference
   ```

2. **Speed Control:** Real-time encoder feedback enables closed-loop speed control:
   - Measure actual wheel speed
   - Compare to target speed
   - Adjust motor PWM to maintain consistent speed

3. **Position Tracking:** Combined with IMU heading, encoder distance enables dead reckoning:
   - Track X, Y position on the field
   - Validate LiDAR-based localization
   - Detect wheel slip (encoder shows no movement despite motor running)

4. **Calibration:** Encoder data helps calibrate:
   - Wheel diameter variations
   - Motor performance curves
   - Acceleration/deceleration profiles

**Encoder Processing:**
The XRP board's RP2040 microcontroller handles encoder counting in hardware, preventing missed pulses even during intensive processing tasks.

**Cost:** 23 CAD (including motor modifications)

---

## Power System 

<!-- ⚠️⚠️⚠️ REMINDER: ADD POWER SYSTEM DIAGRAM AND BATTERY PLACEMENT PHOTOS ⚠️⚠️⚠️ -->
<p align="center">
  Power System Layout
</p>

Delta Bot's power system is designed for **high capacity, voltage flexibility, and safety**.

### Battery Configuration

**3× 1500mAh LiPo Batteries**
- **Voltage:** 7.4V (2S configuration) per battery
- **Capacity:** 1500mAh per battery = 4500mAh total
- **Discharge Rate:** 25C (sufficient for motor current spikes)
- **Configuration:** Can be wired in parallel (7.4V, 4500mAh) or series (22.2V, 1500mAh) depending on power requirements
- **Weight:** ~120g total
- **Cost:** 18 CAD × 3 = 54 CAD

<!-- ⚠️⚠️⚠️ REMINDER: ADD BATTERY RUNTIME TEST DATA ⚠️⚠️⚠️ -->

**Battery Life:**
- Estimated runtime: [X] minutes of continuous operation
- Competition run duration: ~3-5 minutes (well within capacity)
- Safety margin: Batteries are never depleted below 20% to preserve lifespan

### Voltage Regulation

Different components require different voltages, necessitating a multi-stage voltage regulation system:

**Voltage Regulator System (Cost: 50 CAD)**

1. **7.4V → 5V Step-Down Regulator:**
   - Powers: Raspberry Pi 5 (5V/5A requirement)
   - Type: High-efficiency buck converter
   - Current Capacity: 5A continuous

2. **7.4V → 5V Step-Down Regulator (Secondary):**
   - Powers: RPLidar A2M12 (5V/2A requirement)
   - Separate regulator prevents LiDAR current spikes from affecting Pi 5

3. **7.4V Direct:**
   - Powers: XRP board (accepts 7.4V input directly)
   - XRP board has onboard regulators for its components

4. **7.4V → [Motor Voltage] Regulator:**
   - Powers: Custom drive motor
   - May include step-up converter if higher voltage needed

<!-- ⚠️⚠️⚠️ REMINDER: ADD DETAILED POWER DISTRIBUTION DIAGRAM ⚠️⚠️⚠️ -->

### Power Distribution

**Pi HAT (Cost: 30 CAD):**
A custom power distribution board (Pi HAT) mounts directly on the Raspberry Pi 5's GPIO header, providing:
- Clean 5V power delivery to Pi 5
- Fused protection circuits
- Power switching (on/off control)
- LED status indicators

### Safety Features

1. **Fused Connections:** Each major component has inline fuses to prevent damage from short circuits
2. **Low-Voltage Cutoff:** Software monitors battery voltage and prevents over-discharge
3. **Current Monitoring:** Detect abnormal current draw (stalled motor, short circuits)
4. **Emergency Stop:** Physical button to immediately cut all power

---

## Circuit Diagram 

<!-- ⚠️⚠️⚠️ REMINDER: CREATE AND ADD COMPLETE CIRCUIT DIAGRAM ⚠️⚠️⚠️ -->
<!-- Include: Battery connections, voltage regulators, all sensor connections, motor driver, servo, communication lines (UART, I2C) -->

<p align="center">
  Delta Bot Complete Circuit Diagram
</p>

**Diagram shows:**
- Power distribution from batteries through voltage regulators
- Raspberry Pi 5 connections (USB for camera and LiDAR, GPIO for UART to XRP)
- XRP board connections (motor driver, servo, IMU, encoder, ultrasonic)
- Communication protocols (UART between Pi and XRP, I2C for IMU)
- Ground connections and power planes

---

# Software Architecture 

Delta Bot's software is designed as a modular, multi-threaded system where each subsystem operates independently while sharing data through a central coordination layer.

## Code Structure 

<!-- ⚠️⚠️⚠️ REMINDER: ADD SOFTWARE ARCHITECTURE DIAGRAM ⚠️⚠️⚠️ -->

### File Organization

```
delta-bot/
│
├── main.py                  # Main control loop and state machine
├── config.py                # Configuration parameters and constants
│
├── sensors/
│   ├── lidar.py            # RPLidar data acquisition and processing
│   ├── camera.py           # PiCam2 image capture and preprocessing
│   ├── imu.py              # IMU data reading and fusion
│   ├── ultrasonic.py       # Ultrasonic distance measurement
│   └── encoder.py          # Motor encoder position tracking
│
├── vision/
│   ├── color_detection.py  # HSV-based color threshold detection
│   ├── obstacle_detection.py  # Red/green traffic sign detection
│   ├── parking_detection.py   # Magenta parking wall detection
│   └── line_detection.py      # Orange/blue turn line detection
│
├── navigation/
│   ├── mapping.py          # LiDAR-based map building
│   ├── path_planning.py    # Route calculation and obstacle avoidance
│   ├── localization.py     # Position estimation using sensor fusion
│   └── turn_control.py     # Precise turning using IMU
│
├── control/
│   ├── motor_control.py    # Motor speed and direction control
│   ├── servo_control.py    # Steering angle control
│   └── pid_controller.py   # PID implementation for stable control
│
├── communication/
│   └── xrp_interface.py    # Serial UART communication with XRP board
│
└── utils/
    ├── data_logger.py      # Performance data logging
    └── helpers.py          # Utility functions
```

### Programming Languages

- **Python 3.11:** All Raspberry Pi 5 code (sensor processing, vision, navigation, high-level control)
- **MicroPython:** XRP board code (motor drivers, servo control, encoder reading, IMU interfacing)

### Libraries Used

**Raspberry Pi 5 (Python):**
- **OpenCV (cv2):** Computer vision and image processing
- **rpicam2:** Raspberry Pi camera interface
- **NumPy:** Numerical computations and array operations
- **Pillow (PIL):** Image manipulation
- **regex (re):** Pattern matching and data parsing
- **serial (PySerial):** UART communication with XRP board
- **rplidar:** LiDAR data acquisition library

**XRP Board (MicroPython):**
- **XRPLib:** Official XRP board library for motor control, servo control, and sensor interfaces
- **machine:** Low-level hardware control (UART, I2C, PWM)

---

## Computer Vision 

<!-- ⚠️⚠️⚠️ REMINDER: ADD COMPUTER VISION PROCESSING PIPELINE DIAGRAM ⚠️⚠️⚠️ -->

Delta Bot's vision system uses **HSV color space** instead of RGB for robust color detection under varying lighting conditions.

### Color Detection Pipeline

1. **Image Capture:** PiCam2 captures 1920×1080 frames at 30fps

2. **Color Space Conversion:** Convert BGR (OpenCV default) → HSV
   - **Hue:** Color type (0-180° in OpenCV)
   - **Saturation:** Color intensity (0-255)
   - **Value:** Brightness (0-255)

3. **Color Thresholding:** Define HSV ranges for each color:

<!-- ⚠️⚠️⚠️ REMINDER: ADD YOUR ACTUAL HSV THRESHOLD VALUES HERE ⚠️⚠️⚠️ -->

```python
# Example HSV thresholds (adjust based on testing)
RED_LOWER = np.array([0, 120, 70])
RED_UPPER = np.array([10, 255, 255])

GREEN_LOWER = np.array([40, 50, 50])
GREEN_UPPER = np.array([80, 255, 255])

ORANGE_LOWER = np.array([10, 100, 100])
ORANGE_UPPER = np.array([25, 255, 255])

BLUE_LOWER = np.array([100, 150, 0])
BLUE_UPPER = np.array([130, 255, 255])

MAGENTA_LOWER = np.array([140, 50, 50])
MAGENTA_UPPER = np.array([170, 255, 255])
```

4. **Morphological Operations:** Clean up noise
   - Erosion: Remove small false positives
   - Dilation: Fill gaps in detected regions

5. **Contour Detection:** Find connected regions of detected colors

6. **Bounding Box Creation:** Draw rectangles around detected objects

7. **Centroid Calculation:** Find center point (x, y) of each bounding box

8. **Object Classification:** Determine object type based on:
   - Color (red/green obstacle, orange/blue line, magenta parking)
   - Size (filter out small noise)
   - Shape (aspect ratio)
   - Position in frame

### Frame Processing Rate

- **Target:** 30 fps (real-time)
- **Actual:** Achieved on Raspberry Pi 5 (unlike Pi 4 which struggled)
- **Latency:** <50ms from capture to decision

---

## Sensor Fusion 

<!-- ⚠️⚠️⚠️ REMINDER: ADD SENSOR FUSION DIAGRAM SHOWING HOW DATA COMBINES ⚠️⚠️⚠️ -->

Delta Bot combines data from five sensors to build a comprehensive understanding of its environment:

### Multi-Sensor Integration

1. **LiDAR (Primary Mapping):**
   - Builds 2D occupancy grid of environment
   - Detects walls, obstacles, and free space
   - Provides 360° awareness

2. **Camera (Object Recognition):**
   - Identifies traffic sign colors (red/green)
   - Detects turn lines (orange/blue)
   - Locates parking walls (magenta)

3. **IMU (Orientation):**
   - Tracks robot heading (angle)
   - Measures angular velocity during turns
   - Detects unexpected rotations

4. **Encoder (Odometry):**
   - Measures distance traveled
   - Calculates speed
   - Detects wheel slip

5. **Ultrasonic (Backup):**
   - Validates front obstacle detection
   - Close-range safety checks

### Complementary Strengths

Each sensor compensates for others' weaknesses:
- **LiDAR provides spatial awareness** but can't identify colors → Camera adds color recognition
- **Camera identifies objects** but can't measure precise distances → LiDAR provides exact measurements
- **Encoder tracks distance** but accumulates error over time → LiDAR corrects position drift
- **IMU tracks heading** but drifts over time → LiDAR wall alignment corrects drift

---

## Communication Protocol 

### Raspberry Pi 5 ↔ XRP Board (UART Serial)

**Connection:**
- **Pi 5 TX** (GPIO 14) → **XRP RX**
- **Pi 5 RX** (GPIO 15) → **XRP TX**
- **Baud Rate:** 115200
- **Protocol:** ASCII commands with newline termination

**Command Structure:**

**Pi 5 → XRP (Commands):**
```
MOTOR:<speed>       # Set motor speed (-100 to 100)
SERVO:<angle>       # Set steering angle (-45 to 45)
STOP                # Emergency stop
GET_IMU             # Request IMU data
GET_ENCODER         # Request encoder position
```

**XRP → Pi 5 (Responses):**
```
IMU:<heading>,<angular_velocity>
ENCODER:<position>,<speed>
ACK:<command>       # Acknowledge command received
```

**Error Handling:**
- Timeouts if no response within 100ms
- Checksum validation (optional)
- Automatic reconnection on communication failure

---

# Obstacle Management 

Delta Bot's navigation strategy evolved through extensive testing to balance speed, accuracy, and robustness.

## Qualification Round Strategy 

<!-- ⚠️⚠️⚠️ REMINDER: ADD QUALIFICATION ROUND STRATEGY DIAGRAM ⚠️⚠️⚠️ -->

**Objective:** Complete 3 laps as fast as possible, turning at orange or blue corner lines.

### Algorithm Overview

1. **Track Mapping Phase (First Lap):**
   - Use LiDAR to build a complete map of track boundaries
   - Identify wall positions and track dimensions
   - Calculate optimal racing line (path farthest from walls for maximum speed)

2. **Turn Detection:**
   - LiDAR detects gaps in walls (corners)
   - No reliance on color detection in qualification round
   - Turn trigger: LiDAR identifies corner geometry

3. **Turning Sequence:**
   - Approach corner at moderate speed
   - Slow down slightly before turn
   - Use IMU to execute precise 90° turn
   - Accelerate out of corner

4. **Straight-Line Navigation:**
   - Maintain center of track using LiDAR wall distance measurements
   - Simulated PID keeps robot straight using IMU heading
   - Encoder confirms distance traveled

5. **Lap Counting:**
   - Track number of 90° turns completed (12 turns = 3 laps)
   - After 12 turns, proceed to finish area

### Performance Metrics

- **Best Lap Time:** 14 seconds
- **Consistency:** [Add consistency data if available]
- **Reliability:** Successfully completes 3 laps in >X% of attempts

---

## Obstacle Round Strategy 

<!-- ⚠️⚠️⚠️ REMINDER: ADD OBSTACLE AVOIDANCE STRATEGY DIAGRAM WITH EXAMPLES ⚠️⚠️⚠️ -->

**Objective:** Complete 3 laps while avoiding red and green traffic signs, with a mandatory U-turn if the last obstacle before lap 3 is red.

### Detection System

1. **Camera Continuously Scans** for red and green objects
2. **HSV Color Filtering** isolates potential obstacles
3. **Bounding Box Creation** around detected colors
4. **Centroid Calculation** determines obstacle center position
5. **Nearest Obstacle Selection:** Robot prioritizes closest detected obstacle

### Avoidance Decision Logic

```
IF red obstacle detected:
    Turn RIGHT to avoid
    
IF green obstacle detected:
    Turn LEFT to avoid
    
IF no obstacles detected:
    Continue straight using qualification round navigation
```

### Avoidance Execution

1. **LiDAR Validates Available Space:**
   - Check if right side (for red) or left side (for green) has sufficient clearance
   - Measure distance to walls in avoidance direction
   - Ensure no collision with track boundaries

2. **Calculate Avoidance Angle:**
   - Based on obstacle distance and position
   - Dynamically adjusted using camera centroid
   - Confirmed safe by LiDAR

3. **IMU-Controlled Avoidance Maneuver:**
   - Turn at calculated angle
   - Maintain angle while passing obstacle
   - Return to center line after clearing obstacle

4. **Encoder Confirms Distance:**
   - Track distance traveled during avoidance
   - Ensure full clearance before returning to center

### U-Turn Logic

**U-Turn Trigger Conditions:**
```
IF (lap_count == 2) AND (obstacles_remaining == 1) AND (last_obstacle == RED):
    Execute U-turn sequence
    Reverse direction for lap 3
```

**U-Turn Execution:**
1. Complete avoidance of final red obstacle
2. Move forward additional distance to clear obstacle zone
3. Execute 180° turn using IMU (precise angle critical)
4. Update internal direction variable (clockwise ↔ counterclockwise)
5. Continue lap 3 in opposite direction

**Challenge:** Accurately counting obstacles and identifying the "last" obstacle before lap 3 requires:
- Reliable obstacle detection (no false positives/negatives)
- Accurate lap counting (based on turn counting)
- Robust logic to handle edge cases (obstacles near corners)

### Performance Metrics

- **Obstacle Avoidance Success Rate:** [Add success percentage]
- **U-Turn Success Rate:** [Add success percentage]
- **Best Obstacle Round Score:** 10.0 (14 points)

---

## Parking Challenge 

<!-- ⚠️⚠️⚠️ REMINDER: ADD PARKING CHALLENGE SEQUENCE DIAGRAMS ⚠️⚠️⚠️ -->

**Objective:** After completing obstacle rounds, locate and parallel park between magenta walls.

### Parking Detection

1. **Camera Scans for Magenta Color:**
   - Continuously search for magenta HSV threshold matches
   - Create bounding boxes around detected magenta regions

2. **LiDAR Detects Gap:**
   - Measure wall distances in all directions
   - Identify gap in walls (parking space opening)
   - Measure gap width to confirm sufficient space

3. **Cross-Validation:**
   - Both camera (magenta walls) AND LiDAR (gap) must confirm parking space
   - Reduces false positives (random magenta objects)

### Parking Sequence

**Phase 1: Positioning**
1. Drive parallel to parking space
2. Position robot so parking space is to the side
3. Stop when parking space is aligned with robot center

**Phase 2: Entry Turn**
1. Turn steering toward parking space (IMU-controlled angle)
2. Drive forward into parking space at slow speed
3. LiDAR monitors distance to back wall

**Phase 3: Alignment**
1. Straighten steering (servo to center position)
2. Continue forward until LiDAR detects appropriate distance from back wall
3. Stop precisely between front and back magenta walls

**Phase 4: Final Positioning**
1. Minor adjustments if needed (reverse slightly, straighten)
2. Confirm parallel alignment with walls using IMU
3. Complete stop - parking successful!

### Challenges Faced

<!-- ⚠️⚠️⚠️ REMINDER: ADD DETAILS ABOUT PARKING CHALLENGES AND WHY NOT SUCCESSFUL YET ⚠️⚠️⚠️ -->

**Current Status:** Parking challenge not yet successfully completed in competition.

**Primary Difficulties:**
- [Add specific challenges: magenta detection reliability, alignment precision, timing, etc.]
- [Explain what needs improvement]

**Planned Improvements:**
- [List specific improvements being developed]

---

# Code Implementation 

<!-- ⚠️⚠️⚠️ REMINDER: ADD ALL CODE SECTIONS BELOW WITH YOUR ACTUAL CODE ⚠️⚠️⚠️ -->
<!-- For each section, add the relevant Python/MicroPython code with detailed comments -->

## Main Control Loop 

The main control loop implements a state machine to handle different phases of the competition.

```python
# ⚠️⚠️⚠️ ADD YOUR main.py CODE HERE ⚠️⚠️⚠️
# Include: State machine structure, main loop, state transitions

# Example structure (replace with your actual code):
"""
import time
from sensors import lidar, camera, imu
from navigation import path_planning, turn_control
from control import motor_control, servo_control

class RobotState:
    INIT = 0
    QUALIFICATION = 1
    OBSTACLE_AVOIDANCE = 2
    PARKING_SEARCH = 3
    PARKING = 4
    COMPLETE = 5

def main():
    # Initialize all systems
    state = RobotState.INIT
    
    while True:
        if state == RobotState.INIT:
            # Initialization code
            pass
            
        elif state == RobotState.QUALIFICATION:
            # Qualification round navigation
            pass
            
        elif state == RobotState.OBSTACLE_AVOIDANCE:
            # Obstacle detection and avoidance
            pass
            
        elif state == RobotState.PARKING_SEARCH:
            # Search for parking space
            pass
            
        elif state == RobotState.PARKING:
            # Execute parking maneuver
            pass
            
        elif state == RobotState.COMPLETE:
            # Stop all motors
            break

if __name__ == "__main__":
    main()
"""
```

---

## LiDAR Mapping 

LiDAR data processing creates a 2D occupancy grid map of the environment.

```python
# ⚠️⚠️⚠️ ADD YOUR sensors/lidar.py CODE HERE ⚠️⚠️⚠️
# Include: LiDAR initialization, data acquisition, map building, wall detection

# Example structure (replace with your actual code):
"""
from rplidar import RPLidar
import numpy as np

class LidarProcessor:
    def __init__(self, port='/dev/ttyUSB0'):
        self.lidar = RPLidar(port)
        self.scan_data = []
        
    def start_scanning(self):
        # Start LiDAR motor and scanning
        pass
        
    def get_scan(self):
        # Retrieve one complete 360° scan
        # Returns: list of (angle, distance) tuples
        pass
        
    def build_map(self, scans):
        # Convert scan data to occupancy grid
        pass
        
    def detect_walls(self, scan):
        # Identify wall segments from scan data
        pass
        
    def detect_gaps(self, scan):
        # Find gaps in walls (corners, parking space)
        pass
"""
```

---

## Color Detection 

Camera-based color detection for obstacles, lines, and parking walls.

```python
# ⚠️⚠️⚠️ ADD YOUR vision/color_detection.py CODE HERE ⚠️⚠️⚠️
# Include: HSV thresholding, contour detection, bounding boxes, centroid calculation

# Example structure (replace with your actual code):
"""
import cv2
import numpy as np
from picamera2 import Picamera2

class ColorDetector:
    def __init__(self):
        self.camera = Picamera2()
        self.camera.configure(self.camera.create_preview_configuration())
        self.camera.start()
        
        # HSV thresholds for different colors
        self.RED_LOWER = np.array([0, 120, 70])
        self.RED_UPPER = np.array([10, 255, 255])
        # ... (add all color thresholds)
        
    def capture_frame(self):
        # Capture image from camera
        pass
        
    def detect_color(self, frame, lower_hsv, upper_hsv):
        # Detect specific color in frame
        # Returns: bounding boxes and centroids
        pass
        
    def detect_obstacles(self, frame):
        # Detect red and green traffic signs
        pass
        
    def detect_parking_walls(self, frame):
        # Detect magenta parking walls
        pass
        
    def detect_turn_lines(self, frame):
        # Detect orange and blue turn lines
        pass
"""
```

---

## IMU Integration 

IMU data processing for precise heading tracking and turn execution.

```python
# ⚠️⚠️⚠️ ADD YOUR sensors/imu.py CODE HERE ⚠️⚠️⚠️
# Include: IMU initialization, gyroscope reading, angle integration, drift compensation

# Example structure (replace with your actual code):
"""
import time

class IMUProcessor:
    def __init__(self, xrp_interface):
        self.xrp = xrp_interface
        self.current_heading = 0.0
        self.last_update_time = time.time()
        
    def calibrate_drift(self):
        # Measure and compensate for gyroscope drift
        pass
        
    def update_heading(self):
        # Read angular velocity from IMU
        # Integrate to calculate current heading
        pass
        
    def get_heading(self):
        # Return current heading in degrees (0-360)
        return self.current_heading
        
    def turn_to_angle(self, target_angle):
        # Execute turn to reach target heading
        pass
        
    def reset_heading(self):
        # Reset heading to 0 (useful after calibration)
        self.current_heading = 0.0
"""
```

---

## Motor Control 

Motor speed and direction control with encoder feedback.

```python
# ⚠️⚠️⚠️ ADD YOUR control/motor_control.py CODE HERE ⚠️⚠️⚠️
# Include: Motor commands, speed control, encoder reading, distance calculation

# Example structure (replace with your actual code):
"""
class MotorController:
    def __init__(self, xrp_interface):
        self.xrp = xrp_interface
        self.wheel_diameter = 65  # mm
        self.encoder_pulses_per_rev = 360  # adjust to your encoder
        
    def set_speed(self, speed):
        # Set motor speed (-100 to 100)
        # Negative = reverse, Positive = forward
        command = f"MOTOR:{speed}\n"
        self.xrp.send_command(command)
        
    def stop(self):
        # Stop motor
        self.set_speed(0)
        
    def get_encoder_position(self):
        # Request encoder position from XRP
        pass
        
    def get_distance_traveled(self):
        # Calculate distance from encoder pulses
        pass
        
    def drive_distance(self, distance_cm, speed):
        # Drive forward/backward a specific distance
        pass
"""
```

---

## Obstacle Avoidance 

Complete obstacle detection and avoidance implementation.

```python
# ⚠️⚠️⚠️ ADD YOUR navigation/obstacle_avoidance.py CODE HERE ⚠️⚠️⚠️
# Include: Obstacle detection logic, avoidance angle calculation, execution

# Example structure (replace with your actual code):
"""
class ObstacleAvoider:
    def __init__(self, camera, lidar, imu, motor, servo):
        self.camera = camera
        self.lidar = lidar
        self.imu = imu
        self.motor = motor
        self.servo = servo
        
        self.obstacle_count = 0
        self.lap_count = 0
        
    def detect_nearest_obstacle(self):
        # Use camera to find nearest red or green obstacle
        # Returns: (color, centroid, distance)
        pass
        
    def calculate_avoidance_angle(self, obstacle_color, obstacle_position):
        # Calculate steering angle to avoid obstacle
        # Red → turn right, Green → turn left
        pass
        
    def validate_clearance(self, direction):
        # Use LiDAR to ensure safe clearance in avoidance direction
        pass
        
    def execute_avoidance(self, obstacle_color):
        # Complete avoidance maneuver
        pass
        
    def check_uturn_condition(self):
        # Determine if U-turn is required
        if self.lap_count == 2 and self.last_obstacle_color == 'RED':
            return True
        return False
        
    def execute_uturn(self):
        # Perform 180° turn using IMU
        pass
"""
```

---

# Robot Construction Guide 

This step-by-step guide will help you replicate Delta Bot from scratch.

## Prerequisites

**Tools Required:**
- 3D printer (we used Creality K1C)
- Soldering iron and solder
- Wire strippers
- Screwdrivers (Phillips and flathead)
- Hot glue gun (for temporary mounting/testing)
- Multimeter (for electrical testing)
- Computer with Arduino IDE and Python 3.11+

**Materials Required:**
- All components listed in [Cost Report](#cost-report)
- PLA+ filament (approximately 500g)
- Jumper wires (male-to-male, male-to-female, female-to-female)
- Heat shrink tubing
- Zip ties for cable management
- M3 screws and nuts (various lengths)

---

## Step 1: 3D Print All Components

<!-- ⚠️⚠️⚠️ REMINDER: ENSURE ALL STL FILES ARE IN ./3d-models/ FOLDER ⚠️⚠️⚠️ -->

**Printing Settings (Creality K1C):**
- **Material:** PLA+
- **Layer Height:** 0.2mm
- **Infill:** 20%
- **Print Speed:** 150mm/s
- **Supports:** Yes (for overhangs > 45°)
- **Brim:** Yes (for large flat parts to prevent warping)

**Components to Print:**

1. **Chassis Components:**
   - `chassis_base.stl` (main platform)
   - `chassis_front.stl` (front section)
   - `chassis_rear.stl` (rear section)

2. **Motor System:**
   - `motor_mount_left.stl`
   - `motor_mount_right.stl`
   - `axle_holder_left.stl`
   - `axle_holder_right.stl`
   - `custom_motor_housing.stl`

3. **Steering Components:**
   - `front_axle_left.stl`
   - `front_axle_right.stl`
   - `steering_linkage.stl` (×2)
   - `servo_mount.stl`

4. **Sensor Mounts:**
   - `lidar_tower.stl`
   - `lidar_mounting_plate.stl`
   - `camera_mount.stl`
   - `ultrasonic_bracket.stl`

5. **Electronics Mounting:**
   - `pi5_mounting_tray.stl`
   - `xrp_board_bracket.stl`
   - `battery_compartment.stl`
   - `voltage_regulator_housing.stl`

6. **Cable Management:**
   - `cable_clip.stl` (×10)
   - `wire_routing_channel.stl`

**Print Time:** Approximately 48-60 hours total

**Post-Processing:**
- Remove supports carefully
- Sand any rough edges
- Test fit all parts before assembly

---

## Step 2: Assemble Custom Motor

<!-- ⚠️⚠️⚠️ REMINDER: ADD DETAILED MOTOR ASSEMBLY PHOTOS FOR EACH STEP ⚠️⚠️⚠️ -->

1. **Disassemble TT Motor:**
   - Carefully open motor housing using small screwdriver
   - Remove internal components (keep organized!)
   - Note: Do not lose tiny gears or springs

2. **Prepare Encoder Integration:**
   - Position DG01D-E encoder on motor shaft
   - Ensure encoder disk aligns with optical sensors
   - Test encoder signals before permanent mounting

3. **Modify Motor Housing:**
   - Drill/file slots on both sides for axle pass-through
   - Ensure slots are aligned perfectly (use jig if possible)
   - Smooth all edges to prevent axle friction

4. **Reassemble Motor:**
   - Secure encoder with adhesive or screws
   - Carefully reassemble motor housing
   - Test motor rotation (should spin freely)

5. **Mount to Chassis:**
   - Position motor in custom motor mounts
   - Insert axle through both sides
   - Secure with M3 screws

**Testing:** Connect motor to XRP board and verify encoder readings before proceeding.

---

## Step 3: Assemble Steering System

<!-- ⚠️⚠️⚠️ REMINDER: ADD STEERING ASSEMBLY PHOTOS ⚠️⚠️⚠️ -->

1. **Attach Servo to Mount:**
   - Insert SG90 servo into `servo_mount.stl`
   - Secure with servo screws (usually included with servo)
   - Ensure servo rotates freely

2. **Install Front Axle Holders:**
   - Attach `front_axle_left.stl` and `front_axle_right.stl` to chassis
   - Insert smooth rod or axle pins for rotation

3. **Connect Steering Linkages:**
   - Attach `steering_linkage.stl` pieces to servo horn
   - Connect other ends to front axle holders
   - Adjust lengths for equal left/right steering

4. **Test Steering:**
   - Connect servo to XRP board
   - Test full range of motion (left, center, right)
   - Adjust linkages if needed

---

## Step 4: Install Wheels and Drivetrain

<!-- ⚠️⚠️⚠️ REMINDER: ADD WHEEL INSTALLATION PHOTOS ⚠️⚠️⚠️ -->

1. **Rear Wheels:**
   - Slide 65mm wheels onto rear axle (both sides of motor)
   - Secure with set screws or press-fit hubs
   - Ensure wheels are aligned and parallel

2. **Front Wheels:**
   - Attach 65mm wheels to front axle holders
   - Secure with appropriate fasteners
   - Test steering motion (wheels should turn together)

3. **Test Drive:**
   - Manually roll robot to check for friction
   - Wheels should roll smoothly without wobbling
   - Axles should not bind

---

## Step 5: Mount Electronics

<!-- ⚠️⚠️⚠️ REMINDER: ADD ELECTRONICS MOUNTING PHOTOS FOR EACH COMPONENT ⚠️⚠️⚠️ -->

### Raspberry Pi 5

1. Install NVMe SSD on bottom of Pi 5 (if using)
2. Mount Pi 5 to `pi5_mounting_tray.stl` using M2.5 screws
3. Attach Pi HAT for power distribution
4. Position tray on chassis (center, elevated for airflow)

### XRP Controller Board

1. Mount XRP board to `xrp_board_bracket.stl`
2. Position near motor for short motor wires
3. Secure with M3 screws

### RPLidar A2M12

1. Mount LiDAR to `lidar_mounting_plate.stl`
2. Attach plate to `lidar_tower.stl` (elevate LiDAR for clear view)
3. Secure tower to chassis center
4. Connect USB cable to Raspberry Pi 5

### PiCam2

1. Mount camera to `camera_mount.stl`
2. Angle mount ~15-20° downward
3. Position at front of chassis
4. Connect camera ribbon cable to Pi 5 CSI port

### HC-SR04 Ultrasonic Sensor

1. Insert sensor into `ultrasonic_bracket.stl`
2. Mount bracket at front of chassis (centered)
3. Wire to XRP board GPIO pins

### Batteries and Voltage Regulators

1. Place 3× LiPo batteries in `battery_compartment.stl`
2. Secure with velcro straps (allows easy removal)
3. Mount voltage regulators in `voltage_regulator_housing.stl`
4. Position regulators near batteries to minimize wire length

---

## Step 6: Wiring and Connections

<!-- ⚠️⚠️⚠️ REMINDER: ADD WIRING PHOTOS SHOWING ALL CONNECTIONS ⚠️⚠️⚠️ -->

**Power Distribution:**

1. **Battery to Voltage Regulators:**
   - Connect battery positive to main power switch
   - From switch, branch to all voltage regulators
   - Connect battery negative to common ground

2. **Voltage Regulator Outputs:**
   - 5V Regulator #1 → Raspberry Pi 5 (via Pi HAT)
   - 5V Regulator #2 → RPLidar A2M12
   - 7.4V Direct → XRP Board
   - 7.4V (or adjusted) → Motor driver on XRP

**Data Connections:**

3. **Raspberry Pi 5 Connections:**
   - PiCam2 → CSI camera port
   - RPLidar → USB 3.0 port
   - XRP Board → GPIO UART pins (TX/RX)

4. **XRP Board Connections:**
   - Custom Motor → Motor driver outputs
   - Motor Encoder → Encoder inputs (A, B channels)
   - SG90 Servo → Servo output pin
   - HC-SR04 Ultrasonic → GPIO (Trigger and Echo pins)
   - LSM6DSOX IMU → I2C (built into XRP board)

**Cable Management:**
- Route all wires through `wire_routing_channel.stl`
- Secure wires with `cable_clip.stl` pieces
- Use zip ties for additional security
- Leave some slack for maintenance access

---

## Step 7: Software Installation

### Raspberry Pi 5 Setup

1. **Install Raspberry Pi OS:**
   - Download Raspberry Pi OS (64-bit, desktop recommended)
   - Flash to NVMe SSD using Raspberry Pi Imager
   - Boot Pi 5 and complete initial setup

2. **Install Required Libraries:**
```bash
sudo apt update
sudo apt upgrade
sudo apt install python3-pip python3-opencv
pip3 install numpy pillow pyserial rplidar picamera2
```

3. **Clone Delta Bot Repository:**
```bash
git clone https://github.com/[your-username]/delta-bot-wro2025.git
cd delta-bot-wro2025
```

4. **Configure Permissions:**
```bash
# Add user to dialout group for serial access
sudo usermod -a -G dialout $USER

# Reboot for changes to take effect
sudo reboot
```

### XRP Board Setup

1. **Install XRPLib:**
   - Follow XRP official documentation for MicroPython setup
   - Connect XRP board via USB to computer
   - Upload MicroPython firmware

2. **Upload XRP Code:**
```bash
# Use Thonny IDE or similar to upload code
# Upload all files in /xrp_code/ directory
```

3. **Test XRP Functionality:**
   - Run motor test script
   - Verify servo response
   - Check IMU readings
   - Confirm encoder counting

---

## Step 8: Calibration and Testing

<!-- ⚠️⚠️⚠️ REMINDER: ADD CALIBRATION PROCEDURE PHOTOS/SCREENSHOTS ⚠️⚠️⚠️ -->

### IMU Calibration

1. Place robot on level surface
2. Run IMU calibration script
3. Let robot sit still for 30 seconds
4. Record drift compensation values

### Camera Calibration

1. Print color calibration targets (red, green, orange, blue, magenta)
2. Run color detection calibration script
3. Adjust HSV thresholds until colors detected reliably
4. Save calibration values to config file

### Motor Calibration

1. Measure exact wheel diameter
2. Count encoder pulses per revolution
3. Calculate distance per encoder pulse
4. Update configuration values

### Steering Calibration

1. Find servo center position (wheels straight)
2. Measure maximum left/right angles
3. Update servo angle limits in code

### LiDAR Calibration

1. Verify LiDAR mounting is level
2. Test 360° scanning for blind spots
3. Calibrate distance measurements against known distances

---

## Step 9: Initial Testing

<!-- ⚠️⚠️⚠️ REMINDER: ADD TESTING VIDEO OR PHOTOS ⚠️⚠️⚠️ -->

1. **Static Tests:**
   - Verify all sensors return data
   - Test motor forward/reverse
   - Test servo left/right
   - Check camera image capture

2. **Basic Movement:**
   - Drive forward 1 meter (measure accuracy)
   - Turn 90° using IMU (verify angle)
   - Test obstacle detection with colored objects

3. **Qualification Round Practice:**
   - Set up practice track
   - Run qualification algorithm
   - Measure lap times
   - Debug any issues

4. **Obstacle Round Practice:**
   - Add red/green traffic signs
   - Test obstacle detection and avoidance
   - Practice U-turn sequence
   - Refine avoidance angles

---

# Cost Report 

Complete breakdown of all expenses for Delta Bot's development.

## Electronic Components

| Component | Quantity | Unit Cost (CAD) | Total (CAD) |
|---|---|---|---|
| Raspberry Pi 5 (8GB) | 1 | 140.00 | 140.00 |
| PiCam2 | 1 | 33.00 | 33.00 |
| RPLidar A2M12 | 1 | 210.00 | 210.00 |
| XRP Controller Board (with LSM6DSOX IMU) | 1 | 60.00 | 60.00 |
| Custom TT Motor with DG01D-E Encoder | 1 | 23.00 | 23.00 |
| SG90 9g Micro Servo | 1 | 2.00 | 2.00 |
| HC-SR04 Ultrasonic Sensor | 1 | 14.00 | 14.00 |
| LiPo Battery (1500mAh, 7.4V) | 3 | 18.00 | 54.00 |
| Voltage Regulators (Step-up/Step-down) | 1 set | 50.00 | 50.00 |
| Raspberry Pi HAT | 1 | 30.00 | 30.00 |
| NVMe SSD (256GB) | 1 | 46.00 | 46.00 |
| **Electronics Subtotal** | | | **662.00** |

## Mechanical Components

| Component | Quantity | Unit Cost (CAD) | Total (CAD) |
|---|---|---|---|
| 65mm Tracked Wheels | 4 | 8.00 | 32.00 |
| Steel Axle Rods (2mm-5mm diameter) | Various | 15.00 | 15.00 |
| Bearings and Bushings | Set | 10.00 | 10.00 |
| M3 Screws and Nuts (assorted) | 100+ | 12.00 | 12.00 |
| M2.5 Screws (for Pi mounting) | 20 | 5.00 | 5.00 |
| **Mechanical Subtotal** | | | **74.00** |

## 3D Printing Materials

| Item | Quantity | Unit Cost (CAD) | Total (CAD) |
|---|---|---|---|
| PLA+ Filament (1kg spools) | 1 kg | 35.00 | 35.00 |
| Prototyping Filament (iterations) | 2 kg | 30.00 | 60.00 |
| Filament Dryer (Creality) | 1 | 65.00 | 65.00 |
| **3D Printing Subtotal** | | | **160.00** |

## Wiring and Electrical

| Component | Quantity | Unit Cost (CAD) | Total (CAD) |
|---|---|---|---|
| Jumper Wires (M-M, M-F, F-F sets) | 3 sets | 10.00 | 30.00 |
| Heat Shrink Tubing (assorted) | 1 set | 8.00 | 8.00 |
| Solder and Flux | 1 | 15.00 | 15.00 |
| Zip Ties (cable management) | 100 pack | 5.00 | 5.00 |
| USB Cables (various lengths) | 3 | 8.00 | 24.00 |
| Power Switch | 1 | 6.00 | 6.00 |
| **Wiring Subtotal** | | | **88.00** |

## Parts Tested But Not Used

| Component | Reason Removed | Cost (CAD) |
|---|---|---|
| Raspberry Pi 4 | Insufficient processing power | 120.00 |
| Arduino UNO | Poor camera support | 35.00 |
| PiCam v1.3 Wide Angle | Compatibility issues | 25.00 |
| L298N Motor Driver | Integrated into XRP board | 12.00 |
| 500 RPM DC Motor | Insufficient torque | 18.00 |
| LEGO Wheels | Insufficient grip | 20.00 |
| **Tested Parts Subtotal** | | **230.00** |

## Tools and Equipment

<!-- ⚠️⚠️⚠️ REMINDER: ADD ACTUAL TOOL COSTS IF YOU PURCHASED THEM ⚠️⚠️⚠️ -->

| Tool | Cost (CAD) |
|---|---|
| Creality K1C 3D Printer | [Add cost if purchased] |
| Soldering Station | [Add cost if purchased] |
| Multimeter | [Add cost if purchased] |
| Wire Strippers | [Add cost if purchased] |
| Screwdriver Set | [Add cost if purchased] |
| Hot Glue Gun | [Add cost if purchased] |
| **Tools Subtotal** | **[Add total]** |

## Competition and Miscellaneous

| Item | Cost (CAD) |
|---|---|
| Team Registration Fee | [Add if applicable] |
| Competition Mat (for practice) | [Add if purchased] |
| Traffic Sign Models (3D printed) | 15.00 |
| Shipping and Import Fees | ~50.00 |
| **Miscellaneous Subtotal** | **~65.00** |

---

## Total Cost Summary

| Category | Cost (CAD) |
|---|---|
| Electronic Components | 662.00 |
| Mechanical Components | 74.00 |
| 3D Printing Materials | 160.00 |
| Wiring and Electrical | 88.00 |
| Parts Tested (Not Used) | 230.00 |
| Tools and Equipment | [Add total] |
| Competition and Misc. | ~65.00 |
| **GRAND TOTAL** | **~1,279.00 + Tools** |

*Note: Costs are in Canadian Dollars (CAD). Prices may vary by region and retailer. Some tools may already be owned or borrowed, reducing total cost.*

---

# Testing & Results 

<!-- ⚠️⚠️⚠️ REMINDER: ADD TESTING DATA, GRAPHS, AND PERFORMANCE METRICS ⚠️⚠️⚠️ -->

## Practice Testing

**Test Environment:**
- Official WRO mat provided by national organizers
- 3D printed traffic signs (red and green pillars)
- Controlled indoor lighting

**Qualification Round Testing:**

<!-- ⚠️⚠️⚠️ REMINDER: ADD SUCCESS RATE DATA FROM PRACTICE RUNS ⚠️⚠️⚠️ -->

| Metric | Result |
|---|---|
| Best Lap Time | 14 seconds |
| Average Lap Time | [Add data] |
| Success Rate (3 complete laps) | [Add percentage] |
| Wall Collision Rate | [Add percentage] |

**Obstacle Round Testing:**

| Metric | Result |
|---|---|
| Obstacle Detection Accuracy | [Add percentage] |
| Successful Avoidance Rate | [Add percentage] |
| U-Turn Success Rate | [Add percentage] |
| False Positive Rate | [Add percentage] |

**Parking Challenge Testing:**

| Metric | Result |
|---|---|
| Parking Space Detection Rate | [Add percentage] |
| Successful Parking Completions | [Add number] |
| Average Parking Time | [Add time] |

## Competition Performance

**WRO Pakistan Nationals 2024:**
- **Placement:** 3rd Place
- **Qualification Round:** [Add best time]
- **Obstacle Round Score:** 10.0 (14 points)
- **Parking Challenge:** Not completed successfully

**Key Observations:**
- LiDAR-based navigation proved highly reliable
- IMU turning precision was critical for consistency
- Emergency wiring repair demonstrated robust design
- Parking challenge requires further development

---

# Future Improvements 

Based on six months of development and competition experience, we've identified several areas for enhancement:

## Hardware Improvements

1. **Ackermann Steering Geometry:**
   - Current parallel linkage causes minor tire scrub
   - Implementing true Ackermann would improve turning efficiency
   - Reduce tire wear during extended testing

2. **Brushless Motor Upgrade:**
   - More efficient than current brushed DC motor
   - Better thermal management for sustained performance
   - Longer lifespan and reduced maintenance

3. **Improved Camera Mount:**
   - Add adjustable tilt mechanism
   - Vibration dampening for sharper images
   - Wider field of view lens option

4. **Weight Distribution Optimization:**
   - Lower center of gravity for better handling
   - Balance weight more evenly front-to-back
   - Add adjustable ballast system

5. **Modular Sensor Mounting:**
   - Quick-release sensor mounts for rapid testing
   - Standardized mounting interfaces
   - Tool-free sensor angle adjustment

## Software Improvements

1. **Advanced Path Planning:**
   - Implement A* or RRT path planning algorithms
   - Dynamic re-routing when obstacles move
   - Predictive obstacle motion modeling

2. **Machine Learning Integration:**
   - Train neural network for robust obstacle detection
   - Adaptive color threshold learning
   - Automatic calibration using ML

3. **Sensor Fusion Enhancement:**
   - Kalman filter for combining sensor data
   - Better handling of conflicting sensor readings
   - Weighted sensor confidence based on conditions

4. **Parking Challenge Refinement:**
   - More precise alignment algorithms
   - Multi-point distance verification
   - Iterative positioning correction

5. **Code Optimization:**
   - Reduce processing latency
   - Parallel processing for sensor data
   - More efficient data structures

## Strategy Improvements

1. **Cleaner Turning:**
   - Smoother turn entry and exit
   - Speed optimization through corners
   - Minimal steering corrections post-turn

2. **Adaptive Speed Control:**
   - Variable speed based on track sections
   - Slow for obstacles, fast for straights
   - Smooth acceleration/deceleration curves

3. **Robust Error Recovery:**
   - Detect and recover from localization errors
   - Backup navigation strategies
   - Automatic reset and retry logic

4. **Multi-Strategy System:**
   - Different approaches for different track layouts
   - Automatic strategy selection based on conditions
   - A/B testing framework for strategies

---

# Acknowledgments 

Team Delta K would like to express our gratitude to everyone who supported us throughout this journey:

**Haque Academy**
Thank you to our school for providing facilities, encouragement, and the opportunity to represent Pakistan at the international level. Your support for STEM education and robotics programs has been instrumental in our development.

**Coach Ali Saif**
Thank you for your guidance, patience, and technical expertise. Your mentorship helped us navigate challenges and pushed us to achieve more than we thought possible.

<!-- ⚠️⚠️⚠️ REMINDER: ADD ANY OTHER ACKNOWLEDGMENTS ⚠️⚠️⚠️ -->
<!-- Include: Family members, sponsors, mentors, community support, etc. -->

**[Add additional acknowledgments]:**
- Family members who supported late-night testing sessions
- Any sponsors or donors who provided financial support
- Community members who offered advice or resources
- Online communities (forums, Discord servers) that helped with technical issues

**World Robot Olympiad**
Thank you to WRO Pakistan and WRO International for organizing this incredible competition and providing a platform for young engineers to showcase their skills and learn from peers worldwide.

**Open Source Community**
This project was made possible by countless open-source contributors. We especially thank the developers of:
- OpenCV
- RPLidar Python library
- Raspberry Pi Foundation
- Arduino/MicroPython communities

**National Competition Organizers**
Thank you for providing test mats, traffic signs, and a well-organized competition environment that allowed us to perform at our best.

---

# Resources 

## Documentation Files

All technical documentation, code, and 3D models are available in this repository:

<!-- ⚠️⚠️⚠️ REMINDER: ORGANIZE ALL FILES IN APPROPRIATE FOLDERS ⚠️⚠️⚠️ -->

```
delta-bot-wro2025/
│
├── README.md (this file)
│
├── code/
│   ├── raspberry-pi/         # Python code for Pi 5
│   └── xrp-board/            # MicroPython code for XRP
│
├── 3d-models/                 # STL files for all printed parts
│   ├── chassis/
│   ├── motor-system/
│   ├── steering/
│   ├── sensor-mounts/
│   └── electronics/
│
├── electrical-diagram/        # Circuit diagrams and wiring schematics
│
├── hardware-photos/           # Component and assembly photos
│
├── robot-photos/              # Six-view robot images
│
├── team-photos/               # Team member photos
│
├── testing-videos/            # Performance videos
│
└── documentation/             # Additional technical documents
    ├── calibration-guide.md
    ├── troubleshooting.md
    └── competition-checklist.md
```

## External Resources

**Official WRO Resources:**
- [WRO 2025 Official Rules](https://wro-association.org/competition/season-2025/)
- [Future Engineers Category Guide](https://wro-association.org/)
- [WRO Pakistan National Website](https://wro.org.pk/)

**Component Documentation:**
- [Raspberry Pi 5 Documentation](https://www.raspberrypi.com/documentation/computers/raspberry-pi-5.html)
- [XRP Platform Documentation](https://xrpplatform.org/)
- [RPLidar A2 Documentation](https://www.slamtec.com/en/Lidar/A2)
- [OpenCV Python Tutorials](https://docs.opencv.org/4.x/d6/d00/tutorial_py_root.html)
- [LSM6DSOX IMU Datasheet](https://www.st.com/en/mems-and-sensors/lsm6dsox.html)

**Technical Learning Resources:**
- [Autonomous Navigation Basics](https://en.wikipedia.org/wiki/Autonomous_robot)
- [Computer Vision for Robotics](https://opencv.org/)
- [PID Control Tutorial](https://en.wikipedia.org/wiki/PID_controller)
- [LiDAR SLAM Algorithms](https://en.wikipedia.org/wiki/Simultaneous_localization_and_mapping)

**CAD and 3D Printing:**
- [Fusion 360 (Free for Students)](https://www.autodesk.com/products/fusion-360/students-teachers-educators)
- [Creality K1C User Manual](https://www.creality.com/)
- [3D Printing Best Practices](https://all3dp.com/)

**Community Forums:**
- [Raspberry Pi Forums](https://forums.raspberrypi.com/)
- [WRO Discussion Forums](https://wro-association.org/community/)
- [ROS Robotics Forums](https://discourse.ros.org/)

---

## Project Statistics

**Development Timeline:**
- **Total Development Time:** 6 months
- **Design Iterations:** 4 major versions
- **Code Lines Written:** [Add approximate line count]
- **3D Printed Parts:** 30+ components
- **Testing Hours:** [Add approximate hours]
- **Practice Runs:** [Add number]

**Team Effort:**
- **Total Team Hours:** [Add estimate]
- **Design Meetings:** Weekly sessions
- **Testing Sessions:** 2-3 times per week
- **Documentation Hours:** [Add estimate]

---

# License 

```
MIT License

Copyright (c) 2025 Delta K - Team Pakistan (Kabir, Kosain, Rayyan)

Permission is hereby granted, free of charge, to any person obtaining a copy
of this software and associated documentation files (the "Software"), to deal
in the Software without restriction, including without limitation the rights
to use, copy, modify, merge, publish, distribute, sublicense, and/or sell
copies of the Software, and to permit persons to whom the Software is
furnished to do so, subject to the following conditions:

The above copyright notice and this permission notice shall be included in all
copies or substantial portions of the Software.

THE SOFTWARE IS PROVIDED "AS IS", WITHOUT WARRANTY OF ANY KIND, EXPRESS OR
IMPLIED, INCLUDING BUT NOT LIMITED TO THE WARRANTIES OF MERCHANTABILITY,
FITNESS FOR A PARTICULAR PURPOSE AND NONINFRINGEMENT. IN NO EVENT SHALL THE
AUTHORS OR COPYRIGHT HOLDERS BE LIABLE FOR ANY CLAIM, DAMAGES OR OTHER
LIABILITY, WHETHER IN AN ACTION OF CONTRACT, TORT OR OTHERWISE, ARISING FROM,
OUT OF OR IN CONNECTION WITH THE SOFTWARE OR THE USE OR OTHER DEALINGS IN THE
SOFTWARE.
```

---

## Open Source Commitment

Team Delta K is committed to open-source collaboration and knowledge sharing. All code, CAD files, and documentation in this repository are freely available for:

✅ **Learning and Education:** Study our design decisions and implementation  
✅ **Modification:** Adapt our designs for your own projects  
✅ **Sharing:** Distribute and teach others using our materials  
✅ **Commercial Use:** Use in commercial projects (attribution appreciated)  

**We encourage you to:**
- Fork this repository and build upon our work
- Share improvements and innovations with the community
- Provide feedback and suggestions via GitHub Issues
- Credit Delta K if our work helps your project

**Contributing:**
If you improve upon our design or find bugs, please consider:
1. Opening a GitHub Issue to discuss the changes
2. Submitting a Pull Request with your improvements
3. Documenting your changes clearly

Together, we can advance the state of autonomous robotics education!

---

## Contact Information

<!-- ⚠️⚠️⚠️ REMINDER: ADD TEAM CONTACT INFORMATION ⚠️⚠️⚠️ -->

**Team Delta K**  
Haque Academy, Karachi, Pakistan

**Email:** [Add team email]  
**GitHub:** [Add GitHub organization/repo link]  
**Instagram:** [Add Instagram handle]  
**YouTube:** [Add YouTube channel]  
**Website:** [Add website if available]

**For inquiries about:**
- Technical questions about our robot design
- Collaboration opportunities
- Speaking engagements or presentations
- Media requests

Please reach out via email or open a GitHub issue.

---

## Final Thoughts

Participating in WRO 2025 Future Engineers has been an incredible journey for Team Delta K. From the frustration of Pi 4 camera issues to the panic of melted wires at nationals, from celebrating our first successful autonomous lap to earning 3rd place nationally—every moment taught us invaluable lessons.

**What we learned extends far beyond robotics:**
- **Perseverance:** Four design iterations taught us to embrace failure as learning
- **Teamwork:** Three team members, one shared vision, countless late nights
- **Problem-Solving:** Real engineering means finding creative solutions under pressure
- **Time Management:** Balancing school, robotics, and personal life
- **Documentation:** Sharing knowledge amplifies impact

**To future WRO teams:**

Don't wait for perfect conditions—start building now. Your first robot will be terrible, and that's exactly the point. Each failure reveals what you didn't know you needed to learn. Invest in proper hardware early (yes, that Raspberry Pi 5 is worth it). Document everything, even mistakes. Test relentlessly. And remember: the robot that crosses the finish line is built on the failures of the ones that didn't.

**To our competitors:**

We hope this documentation helps you avoid our mistakes and build upon our successes. Robotics advances fastest when we share openly. May the best robot win—and may we all learn together.

**Our next challenge:**

International competition, here we come! We're already planning improvements: better parking algorithms, smoother turning, and maybe—just maybe—a perfect run.

---

<p align="center">
  <b>Team Delta K - Pakistan</b><br>
  WRO 2025 Future Engineers<br>
  <i>"From Karachi to the World"</i>
</p>

<p align="center">
  Team Delta K Celebrating 3rd Place
</p>

<!-- ⚠️⚠️⚠️ REMINDER: ADD TEAM CELEBRATION PHOTO ⚠️⚠️⚠️ -->

---

## Repository Quick Links

**Essential Files:**
- [Main Robot Code (Raspberry Pi)](./code/raspberry-pi/main.py)
- [XRP Controller Code](./code/xrp-board/xrp_main.py)
- [3D Model Files (STL)](./3d-models/)
- [Circuit Diagram](./electrical-diagram/delta-bot-circuit.png)
- [Construction Guide](#robot-construction-guide)
- [Cost Report](#cost-report)

**Documentation:**
- [Calibration Guide](./documentation/calibration-guide.md)
- [Troubleshooting Guide](./documentation/troubleshooting.md)
- [Competition Checklist](./documentation/competition-checklist.md)

**Media:**
- [Robot Photos](./robot-photos/)
- [Performance Videos](./testing-videos/)
- [Team Photos](./team-photos/)

---

## Version History

**v1.0.0** - January 2025
- Initial release for WRO 2025 International Competition
- Complete documentation of Delta Bot design
- All code, CAD files, and technical specifications included
- National competition 3rd place configuration

**v0.4.0** - December 2024  
- Fourth iteration (competition version)
- Raspberry Pi 5 integration
- Complete LiDAR mapping system
- Obstacle avoidance refined

**v0.3.0** - November 2024
- Third iteration
- Switched to Raspberry Pi 5
- Resolved camera and LiDAR processing issues

**v0.2.0** - October 2024
- Second iteration with Raspberry Pi 4
- LiDAR integration attempted
- Camera communication issues identified

**v0.1.0** - September 2024
- First iteration with Arduino Uno
- Basic ultrasonic navigation
- Identified need for better processing power

---

## Changelog

<!-- ⚠️⚠️⚠️ REMINDER: UPDATE CHANGELOG AS YOU MAKE IMPROVEMENTS ⚠️⚠️⚠️ -->

**Future Updates:**
- [ ] Add parking challenge improvements
- [ ] Optimize turning algorithms
- [ ] Add machine learning obstacle detection
- [ ] Create video tutorials for construction
- [ ] Add simulation environment setup guide
- [ ] Publish competition performance analysis

---

## FAQ

**Q: Can I use this design for my WRO team?**  
A: Absolutely! That's why we made it open source. Feel free to use, modify, and improve upon our design.

**Q: What's the minimum budget to replicate this robot?**  
A: Approximately 1,300 CAD (~$950 USD) for all components, excluding tools. See [Cost Report](#cost-report) for details.

**Q: Why Raspberry Pi 5 instead of Arduino or Pi 4?**  
A: We tried both! Arduino lacks camera support and processing power. Pi 4 couldn't handle LiDAR data in real-time. Pi 5's quad-core 2.4GHz processor was essential for our multi-sensor approach.

**Q: How long did it take to build?**  
A: Six months from first concept to national competition, including four major design iterations.

**Q: What's the hardest part of this project?**  
A: Sensor fusion—combining LiDAR, camera, IMU, and encoder data into coherent decisions. Also, the parking challenge (still working on it!).

**Q: Can this robot work outdoors?**  
A: Not reliably. Camera color detection is very sensitive to lighting. It's optimized for indoor competition lighting.

**Q: What programming experience is needed?**  
A: Intermediate Python (OpenCV, NumPy, object-oriented programming) and basic MicroPython. Our code is well-commented to help learners.

**Q: Why not use ROS (Robot Operating System)?**  
A: ROS is powerful but adds complexity. For WRO's focused tasks, our custom Python architecture was simpler and more performant.

**Q: How can I contribute to this project?**  
A: Fork the repository, make improvements, and submit pull requests! We especially welcome parking challenge improvements and code optimizations.

**Q: Where can I buy the components in Pakistan?**  
A: Most electronics are available from local suppliers in Karachi or online through Daraz.pk. Some specialized items (RPLidar, Raspberry Pi 5) may need to be imported.

---

<p align="center">
  ⭐ If this documentation helped you, please give us a star on GitHub! ⭐
</p>

<p align="center">
  <i>Built with passion in Karachi 🇵🇰 | Competing for the world 🌍</i>
</p>

---

**Last Updated:** January 2025  
**Repository:** github.com/[your-username]/delta-bot-wro2025  
**Competition:** WRO 2025 Future Engineers International  
**Team:** Delta K - Kabir, Kosain, Rayyan  
**Coach:** Ali Saif  
**School:** Haque Academy, Karachi, Pakistan

---

<!-- END OF DOCUMENTATION -->

<!-- ⚠️⚠️⚠️ ============================================ ⚠️⚠️⚠️ -->
<!-- ⚠️⚠️⚠️ COMPLETE REMINDER CHECKLIST FOR KABIR ⚠️⚠️⚠️ -->
<!-- ⚠️⚠️⚠️ ============================================ ⚠️⚠️⚠️ -->

<!-- 
PHOTOS TO ADD:
✓ Team banner image (./banner.png)
✓ All team member photos (./team-photos/)
✓ Team group photo (./team-photos/team-image.jpg)
✓ Team celebration photo (./team-photos/team-celebration.jpg)
✓ Robot photos - 6 views (./robot-photos/)
✓ Custom motor assembly photos (./hardware-photos/)
✓ Steering system photos (./hardware-photos/)
✓ All component mounting photos (./hardware-photos/)
✓ Chassis assembly photos (./hardware-photos/)
✓ Wheel installation photos (./hardware-photos/)
✓ Electronics mounting photos (./hardware-photos/)
✓ Wiring and connections photos (./hardware-photos/)
✓ Power system photos (./hardware-photos/)
✓ Testing and calibration photos

3D MODEL BLUEPRINTS TO ADD:
✓ All STL files in ./3d-models/ folder
✓ Technical drawings/blueprints for each component
✓ Add blueprint images in relevant sections

CODE TO ADD:
✓ Complete Python code for Raspberry Pi 5 (./code/raspberry-pi/)
✓ Complete MicroPython code for XRP board (./code/xrp-board/)
✓ Code for each subsystem:
  - Main control loop (main.py)
  - LiDAR mapping (sensors/lidar.py)
  - Color detection (vision/color_detection.py)
  - IMU integration (sensors/imu.py)
  - Motor control (control/motor_control.py)
  - Obstacle avoidance (navigation/obstacle_avoidance.py)

DIAGRAMS TO CREATE AND ADD:
✓ Complete circuit diagram (./electrical-diagram/)
✓ Software architecture diagram
✓ Sensor fusion diagram
✓ Computer vision pipeline diagram
✓ Qualification round strategy diagram
✓ Obstacle avoidance strategy diagram
✓ Parking challenge sequence diagram
✓ Power distribution diagram

DATA TO FILL IN:
✓ Robot weight measurement
✓ Robot dimensions (L x W x H)
✓ Battery runtime data
✓ Success rate percentages from testing
✓ Actual HSV threshold values used
✓ Tool costs (if purchased)
✓ Total code line count
✓ Testing hours estimate
✓ Practice run statistics
✓ Gear ratio specification
✓ Motor voltage specification

TEXT TO COMPLETE:
✓ Rayyan's detailed description
✓ Coach Ali Saif's detailed description
✓ Team formation story
✓ Team dynamic description
✓ Parking challenge failure analysis
✓ Social media links
✓ Contact information
✓ Any additional acknowledgments

VIDEOS TO UPLOAD:
✓ Competition performance video (YouTube)
✓ Testing videos (./testing-videos/)

ADDITIONAL DOCUMENTS TO CREATE:
✓ Calibration guide (./documentation/calibration-guide.md)
✓ Troubleshooting guide (./documentation/troubleshooting.md)
✓ Competition checklist (./documentation/competition-checklist.md)

REMINDERS FOR ONGOING UPDATES:
✓ Update changelog as improvements are made
✓ Add future improvements to FAQ
✓ Keep version history current
✓ Update performance metrics after international competition
-->

<!-- ⚠️⚠️⚠️ END OF REMINDER CHECKLIST ⚠️⚠️⚠️ -->

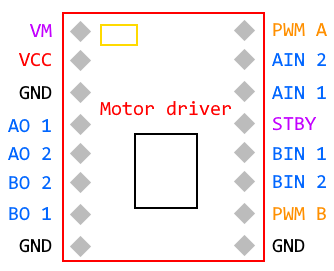
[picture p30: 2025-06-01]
schematics/motor driver pinout.png

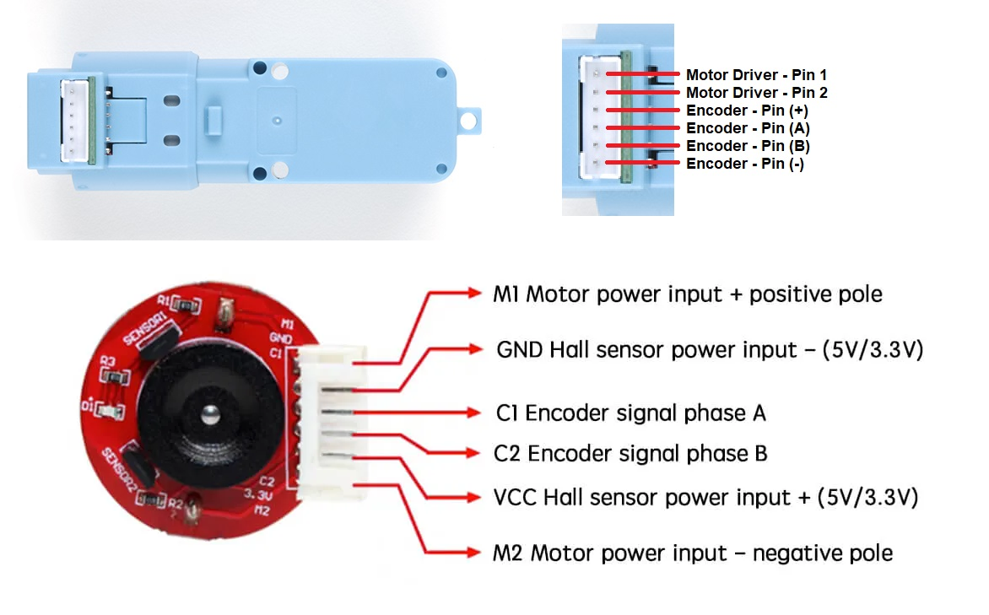
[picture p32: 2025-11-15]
schematics/encoder mismatch.png

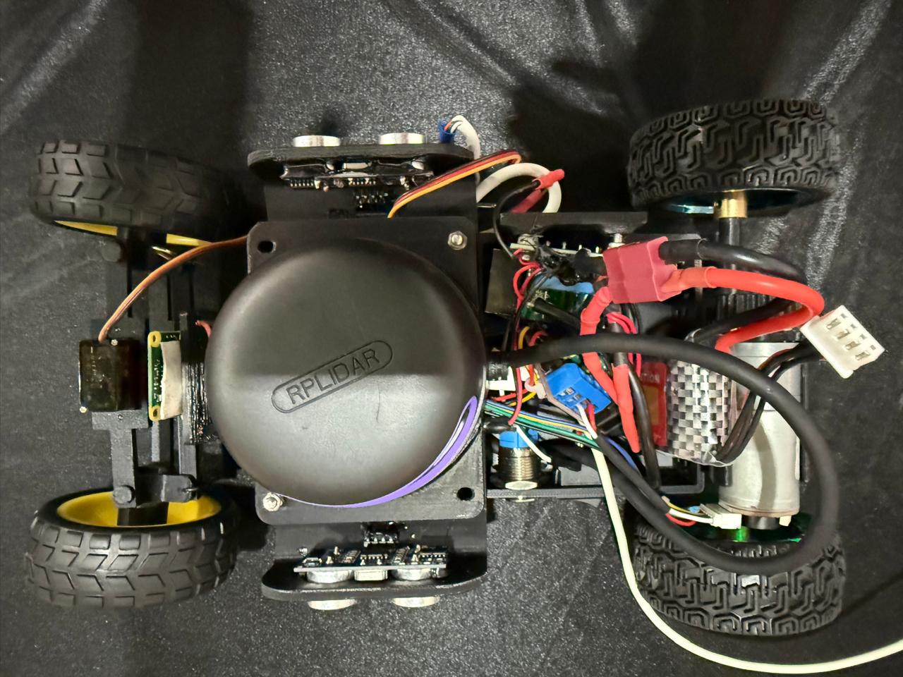
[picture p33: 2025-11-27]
v-photos/recovery/bot7.jpeg

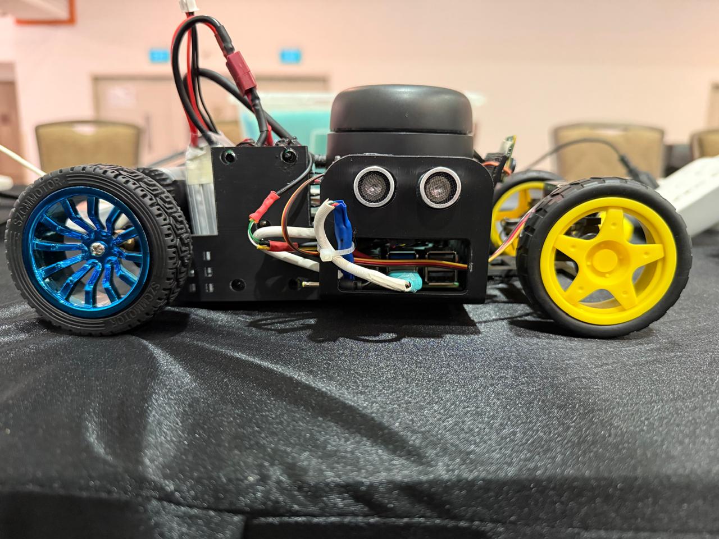
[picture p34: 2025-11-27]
v-photos/recovery/bot9.jpeg

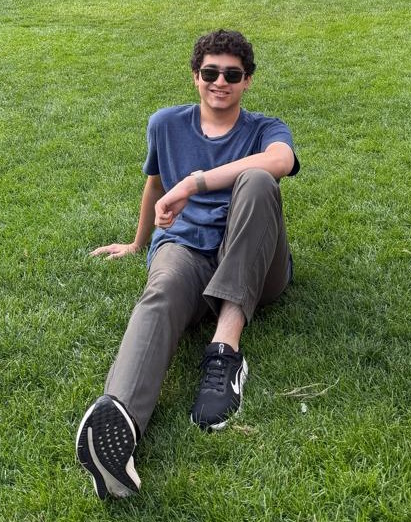
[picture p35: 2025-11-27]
t-photos/kosain.jpeg

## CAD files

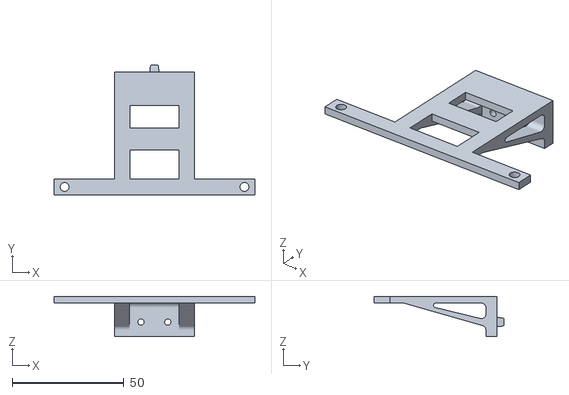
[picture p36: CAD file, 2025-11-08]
models/draft/FrontAssembly10172025.stl
90.0 x 58.0 x 18.0

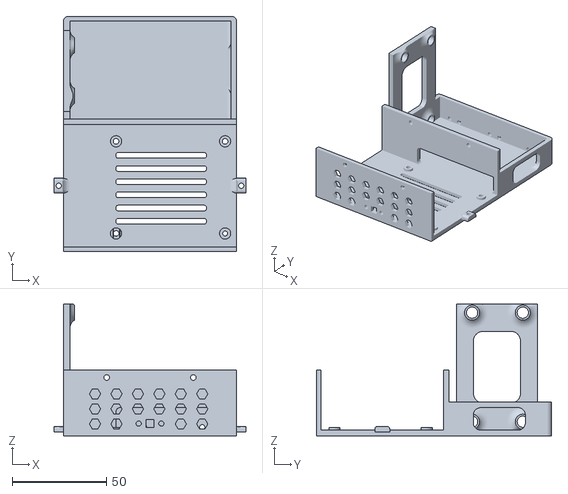
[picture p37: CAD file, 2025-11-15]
models/iteration3/Main BOdy (1).stl
102.1 x 125.0 x 70.0

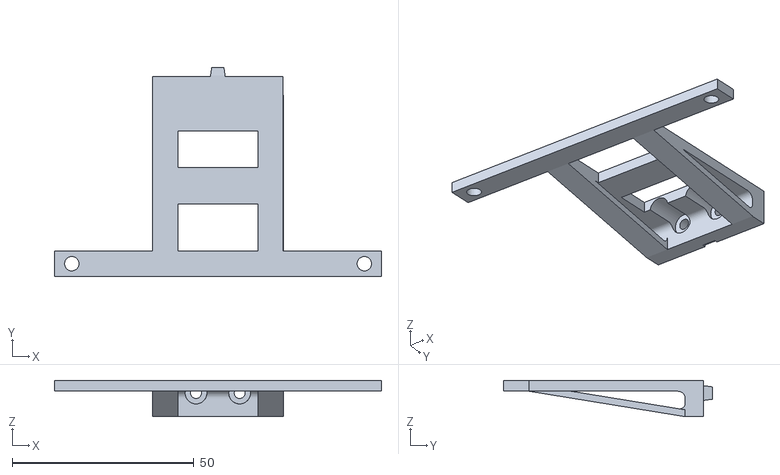
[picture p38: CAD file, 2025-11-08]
models/draft/front assemblymount101925.stl
90.0 x 57.5 x 10.0

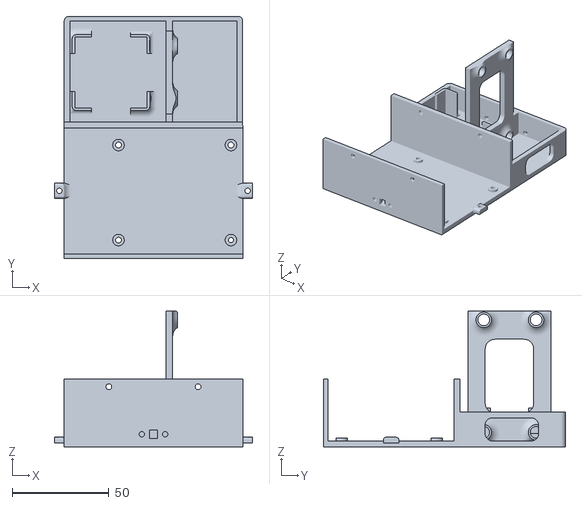
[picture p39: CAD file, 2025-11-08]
models/draft/Main Body101925.stl
102.1 x 125.0 x 70.0

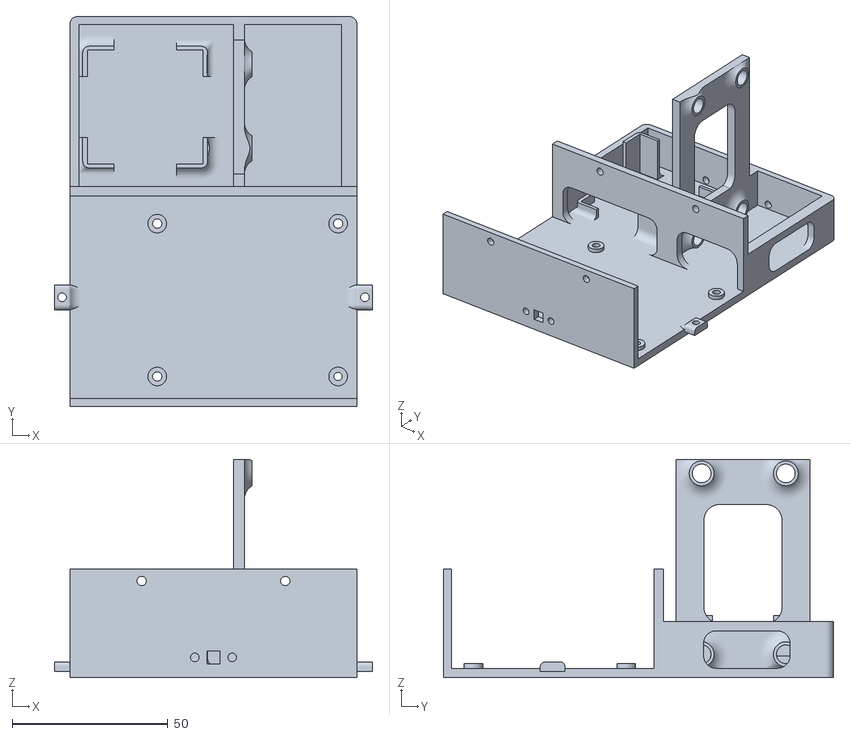
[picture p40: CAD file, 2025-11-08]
models/draft/Main Body V3.stl
102.1 x 125.0 x 70.0

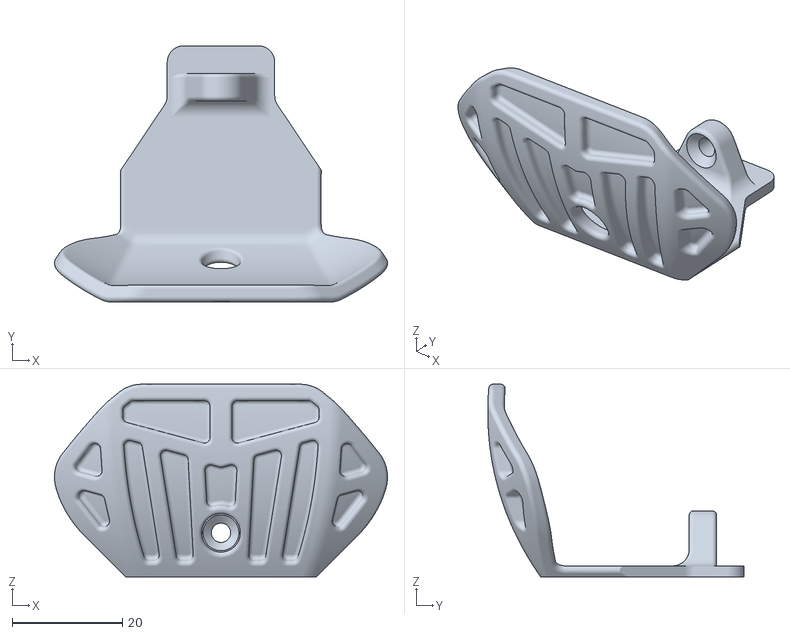
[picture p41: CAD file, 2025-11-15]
models/draft/FrontBumper2.stl
60.5 x 46.6 x 35.0

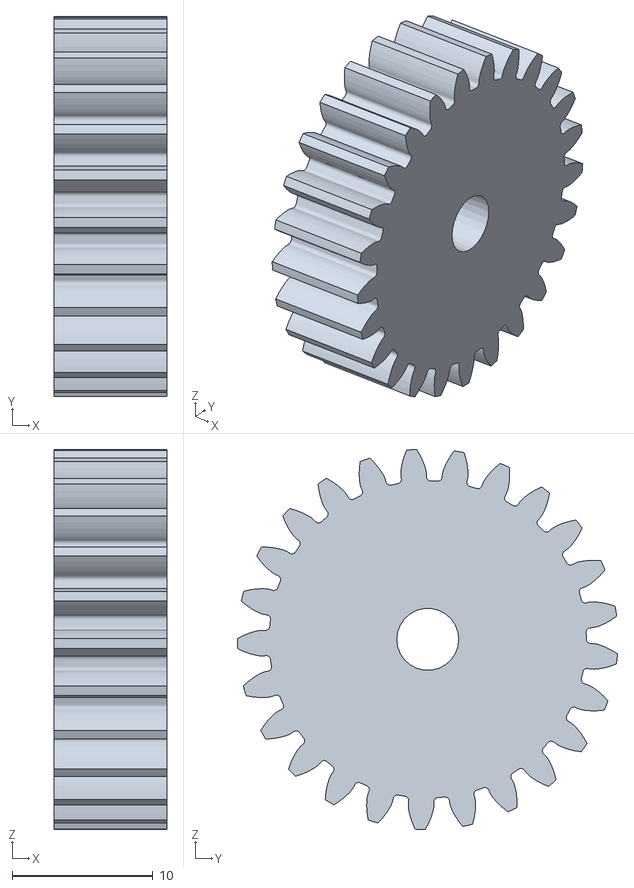
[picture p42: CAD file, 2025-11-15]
models/iteration3/gear.stl
8.00 x 27.0 x 27.0

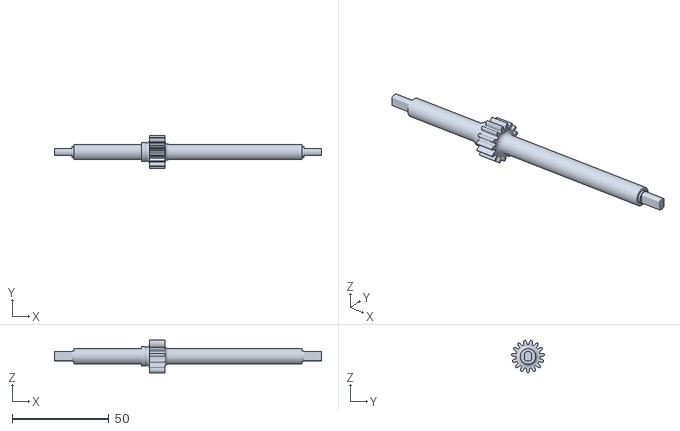
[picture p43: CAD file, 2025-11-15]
models/iteration3/axle (1).stl
138.0 x 17.0 x 16.9

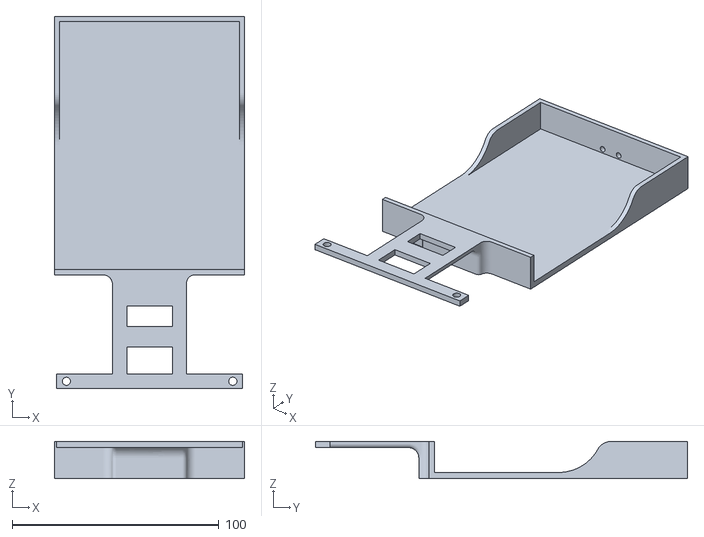
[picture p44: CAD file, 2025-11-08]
models/draft/Car BAse v1.stl
92.1 x 180.0 x 18.0

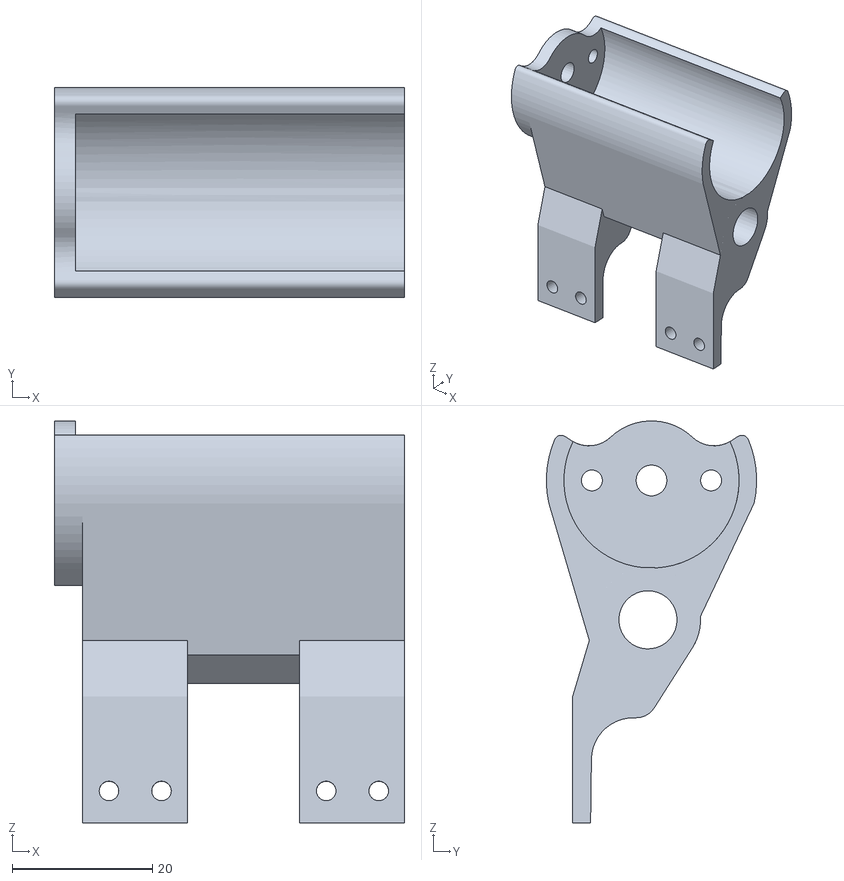
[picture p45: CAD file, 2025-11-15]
models/iteration3/motor mount (1).stl
50.0 x 30.0 x 57.4

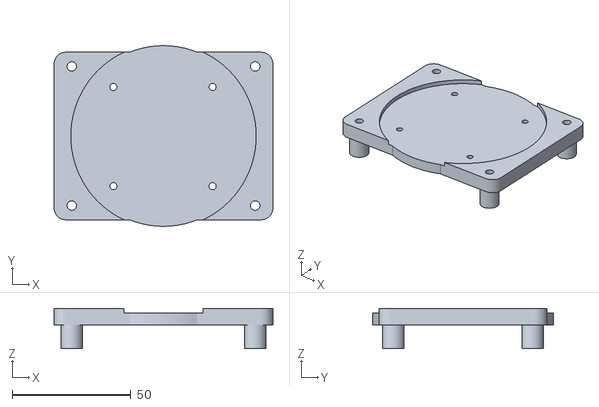
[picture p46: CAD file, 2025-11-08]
models/draft/lidarmount.stl
92.1 x 76.0 x 17.0

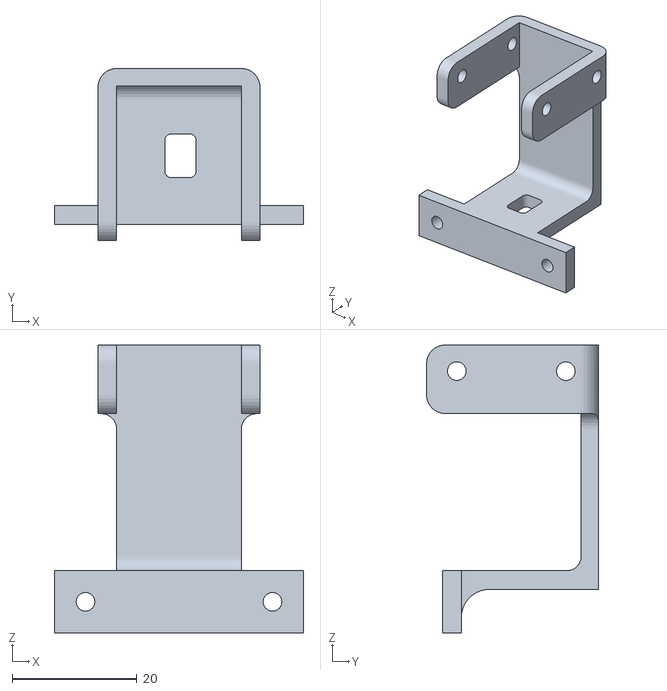
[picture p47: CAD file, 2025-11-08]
models/draft/MotorMount101925 80infil.stl
40.0 x 27.6 x 46.2

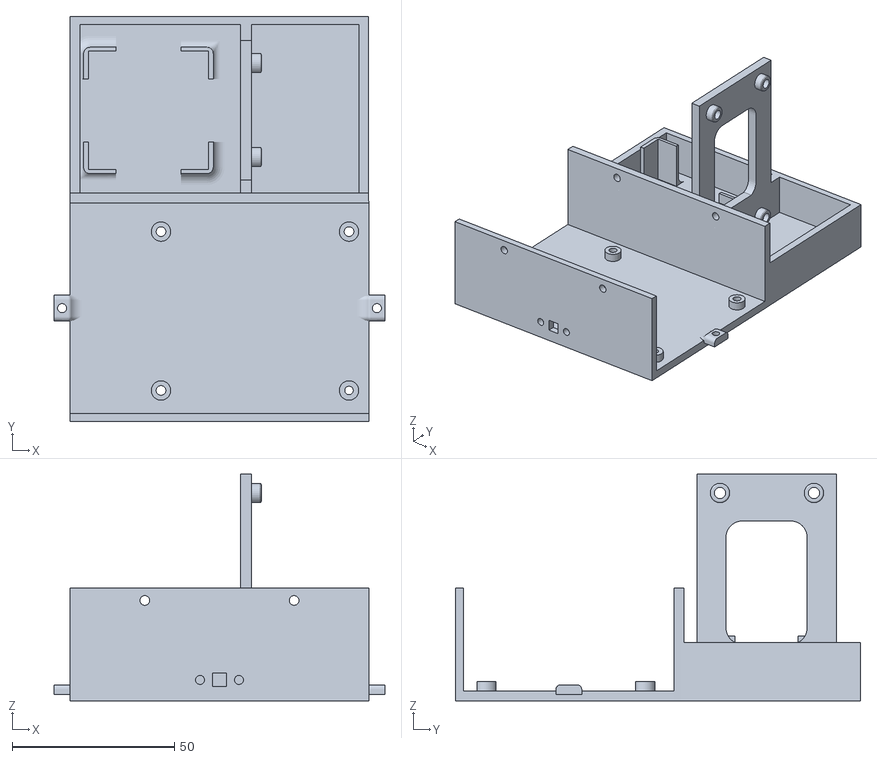
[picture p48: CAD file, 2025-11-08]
models/draft/Base10172025.stl
102.1 x 125.0 x 70.0

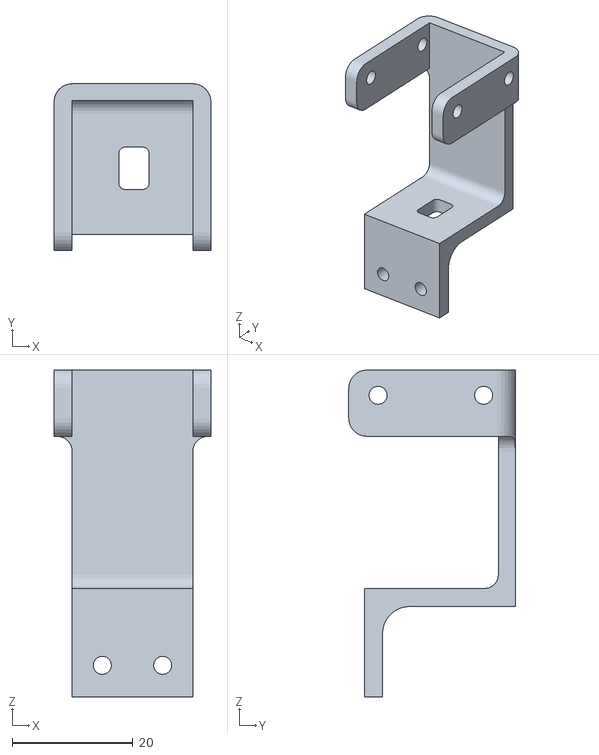
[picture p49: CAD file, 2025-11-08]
models/draft/Motor Mount.stl
26.0 x 27.6 x 54.2

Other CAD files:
models/draft/TopMount10172025.stl
models/draft/LidarMount10172025.stl
models/draft/top part v3.stl
models/draft/Top Part101925.stl
models/draft/BatteryColumn.stl
models/draft/BatteryMount.stl
models/draft/Chassis.stl
models/draft/Chassis.stp
models/draft/CrownGear.stl
models/draft/DetalK Bot.stl
models/draft/ElectronicsColumn.stl
models/draft/FrontBumper1.stl
models/draft/Front_HubCap.stl
models/draft/Front_HubLeft.stl
models/draft/Front_HubMount.stl
models/draft/Front_HubRight.stl
models/draft/Front_HubRight1.stl
models/draft/Front_SuspensionBottomLeft.stl
models/draft/Front_SuspensionBottomRight.stl
models/draft/Front_SuspensionUpperLeft.stl
models/draft/Front_SuspensionUpperRight.stl
models/draft/Front_Wheel.stl
models/draft/Front_WheelLock.stl
models/draft/PinionGear.stl
models/draft/RearSuspension_Bottom.stl
models/draft/RearSuspension_Hub.stl
models/draft/RearSuspension_Upper.stl
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

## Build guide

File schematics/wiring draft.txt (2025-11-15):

Red - 5v
White - 3.3v
Black - GND
Blue - Pi TX
Yellow - Pi RX
Orange - Lidar motor PWM

Lidar color
Red 5V
Black GND
Yellow Lidar TX
Green Lidar RX
Blue PWM

5V - HV
GND - X2
3.3v - LV

PiTX - LV1
PiRX - LV2
PiMotor - LV3

LiRX - HV1
LiTX - HV2
LiMotor - HV3

Motor encoder +
VCC BattV+
GND BattV- XRPV-
INT1 XRP MotorV+
INT2 XRP MotorV-
MotorAV+ NewMotorV+
MotorAV- NewMotorV-

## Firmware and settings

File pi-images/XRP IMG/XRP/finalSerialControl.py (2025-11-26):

from XRPLib.defaults import *
from XRPLib.encoded_motor import EncodedMotor
from XRPLib.servo import Servo
from machine import Pin, time_pulse_us
import sys
import select
import time
from time import sleep as wait
import re

# program params
_PROGPARAMS = {
    'debug_text': False,
    'motor_test': False,
    'routine_rate_hz': 10
    'servo_offset_left': 80
    'servo_offset_center': 90
    'servo_offset_right': 100
}
# --------------

class Ultrasonic:
    def __init__(self, trig_pin, echo_pin, timeout_us=30000):
        self.trig = Pin(trig_pin, mode=Pin.OUT)
        self.echo = Pin(echo_pin, mode=Pin.IN)
        self.timeout_us = timeout_us

    def distance(self):
        '''Returns distance in cm.'''
        # send pulse
        self.trig.value(0)
        time.sleep_us(2)
        self.trig.value(1)
        time.sleep_us(10)
        self.trig.value(0)
        # measure echo time
        pulse_time = time_pulse_us(self.echo, 1, self.timeout_us)
        # convert to cm: sound speed ~343 m/s => ~29.1 us per cm round-trip
        distance = (pulse_time / 2) / 29.1
        return distance

# drive motor and servo motor
driveMtr = EncodedMotor.get_default_encoded_motor(2)
servoMtr = Servo(16)

# ultra sonic left and right
usLeft = Ultrasonic(28, 22)
usRight = Ultrasonic(21, 20)

def mapf(v, inL, inU, outL, outU): # float linear interpolation (similar to arduino's map() function)
    return outL + (v - inL) * (outU - outL) / (inU - inL)
def isnumber(s):
    if len(s) == 0:
        return False
    if s[0] == '-':        # allow leading minus
        s = s[1:]          # strip it
        if len(s) == 0:    # "-" alone is not a number
            return False
    return all('0' <= c <= '9' for c in s)
def setSteerCorrected(steer, debug=False):
    # check type and convert to int if needed
    if isinstance(steer, str):
        if debug: print("steer is a string, attempting to convert to int")
        if not isnumber(steer):
            if debug: print("steer is not numeric or not int")
            return (2, -1) # return error 1 and angle -1 to indicate a fail
        else:
            steer = int(steer)
            if debug: print("converted")
    
    # check range and set servo angle
    softLimits = {
        'left': _PROGPARAMS['servo_offset_left'],
        'right': _PROGPARAMS['servo_offset_right'],
        'center': _PROGPARAMS['servo_offset_center']
    }
    if steer == 0:
        outAngle = 100
        if debug: print(f"Sterring straight ({outAngle}deg)")
    elif -100 <= steer < 0:
        outAngle = mapf(steer, -100, 0, softLimits['left'], softLimits['center'])
        outAngle = int(round(outAngle))
        if debug: print(f"Sterring left {abs(steer)}% ({outAngle}deg)")
    elif 0 < steer <= 100:
        outAngle = mapf(steer, 0, 100, softLimits['center'], softLimits['right'])
        outAngle = int(round(outAngle))
        if debug: print(f"Sterring right {steer}% ({outAngle}deg)")
    else:
        if debug: print("steer is not within range, freeing servo")
        # return (1, -1) # return error 1 and angle -1 to indicate a fail
        servoMtr.free()
        return (0, -1) # return error 0 and indicate servo is freed thru angle being -1
    servoMtr.set_angle(outAngle)

imu.calibrate()

def parseCmd(cmd: str):
    try:
        cmd = cmd.strip().replace('\r', '').replace('\n', '')

        if not cmd:
            return {"unformatted": "empty input"}

        if not (cmd.startswith("<") and cmd.endswith(">")):
            return {"unformatted": "missing angle brackets"}

        # remove angle brackets
        inside = cmd[1:-1]

        pairs = inside.split(';')
        data = {}

        for pair in pairs:
            if not pair.strip():
                continue  # skip empty from final semicolon

            if ':' not in pair:
                return {"unformatted": f"missing ':' in '{pair.strip()}'"}

            key, value = pair.split(':', 1)
            key = key.strip()
            value = value.strip()

            if not value.lstrip('-').isdigit():
                return {"unformatted": f"invalid number '{value}'"}

            data[key] = int(value)

        # Required fields enforcement
        for key in ("motor", "servo"):
            if key not in data:
                return {"unformatted": f"missing key '{key}'"}

        return data

    except Exception as e:
        return {"unformatted": f"unexpected error: {e}"}
        
        
# clear the entire serial buffer so previous data cannot interfere
print("Flushing serial input buffer, please wait...")
i = 0
while select.select([sys.stdin], [], [], 0)[0]:
    i += 1
    print(f"Clearing byte {i}...", end=' ')
    sys.stdin.read(1)
    print(f"\rcleared")
print("Cleared, ready!")

# # testing motor
# print("Testing motor FWD")
# driveMtr.set_effort(0.2)
# wait(1)
# print("Testing motor BKD")
# driveMtr.set_effort(-0.2)
# wait(1)
# driveMtr.coast()

# testing motor ramp speed
if _PROGPARAMS['motor_test']:
    for i in range(0, 100):
        print(f"\rSpeed: {i}%  ", end='')
        # print(f"\rSpeed: [", end='')
        # for j in range(round(i/10)): print('|', end='')
        # for j in range(10 - round(i/10)): print(' ', end='')
        driveMtr.set_effort(i/100.0)
        wait(0.002)
    for i in range(100, 0, -1):
        print(f"\rSpeed: {i}%  ", end='')
        driveMtr.set_effort(i/100.0)
        wait(0.002)
        
    for i in range(0, -100, -1):
        print(f"\rSpeed: {i}%  ", end='')
        driveMtr.set_effort(i/100.0)
        wait(0.002)
    for i in range(-100, 1):
        print(f"\rSpeed: {i}%  ", end='')
        driveMtr.set_effort(i/100.0)
        wait(0.002)
    driveMtr.coast()
    print()

i = 0
while True:
    # Check if there's data waiting on USB
    parseCmdSuccess = True
    if select.select([sys.stdin], [], [], 0)[0]:
        line = sys.stdin.readline()
        line = line.replace('\r', '').replace('\n', '')
        # print("Got:", line)
        if _PROGPARAMS['debug_text']: sys.stdout.write(f"Recv data checked at #{i}:{line}\n")
        
        cmdInput = parseCmd(line)
        if _PROGPARAMS['debug_text']: print("RAW BYTES:", repr(line))
        if "unformatted" in cmdInput: # this is line 122
            if _PROGPARAMS['debug_text']: sys.stdout.write(f"Incoming data is unformatted: {cmdInput['unformatted']}")
        else:
            # fetch and update motor
            mSpeed = cmdInput['motor']
            mSpeed = float(mSpeed)
            mSpeed = mSpeed / 100
            if mSpeed == 0: driveMtr.coast()
            else: driveMtr.set_effort(mSpeed)
            
            # fetch and update servo
            sAngle = cmdInput['servo']
            sAngle = int(sAngle)
            # if sAngle > -1: servoMtr.set_angle(sAngle)
            # else: servoMtr.free();
            setSteerCorrected(sAngle)
            
            if _PROGPARAMS['debug_text']: 
                sys.stdout.write(f"---\n> Parsed motor speed is {mSpeed}%\n")
                sys.stdout.write(f"> Parsed servo angle is {cmdInput['servo']}deg\n---")
            else:
                parseCmdSuccess = False
        if _PROGPARAMS['debug_text']: sys.stdout.write('\n')
            
    else:
        # Do other stuff without blocking
        # print("No data yet...")
        if _PROGPARAMS['debug_text']: sys.stdout.write(f"Check #{i} yields no data...\n")
    
    if _PROGPARAMS['routine_rate_hz'] > 0: wait(1.0 / _PROGPARAMS['routine_rate_hz'])
    # if parseCmdSuccess: sys.stdout.write(f"<i:{i};success:1;>\n\r")
    
    # send sensor output data
    outputData = {
        'i': i,
        # 'dist': rangefinder.distance(),
        # 'accel': f"{imu.get_acc_x()}, {imu.get_acc_y()}, {imu.get_acc_z()}",
        # 'gyro': f"{imu.get_roll()}, {imu.get_heading()}, {imu.get_yaw()}",
        # 'gyrorate': f"{imu.get_gyro_x_rate()}, {imu.get_gyro_y_rate()}, {imu.get_gyro_z_rate()}"
        'accel': f"{imu.get_acc_x()}, {imu.get_acc_y()}",
        'gyroHeading': imu.get_heading(),
        # 'gyroHeadingRate': imu.get_gyro_y_rate()
        'distL': usLeft.distance(),
        'distR': usRight.distance()
    }
    outputItems = []
    outputFormatted = ""
    for k, v in outputData.items():
        outputItems.append(f"{k}: {v}")
    sys.stdout.write("<" + "; ".join(outputItems) + ";>\n\r")
    # sys.stdout.flush()
    
    i += 1

# available variables from defaults: left_motor, right_motor, drivetrain,
#      imu, rangefinder, reflectance, servo_one, board, webserver
# Write your code Here

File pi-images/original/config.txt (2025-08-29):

# For more options and information see
# http://rptl.io/configtxt
# Some settings may impact device functionality. See link above for details

# Uncomment some or all of these to enable the optional hardware interfaces
dtparam=i2c_arm=on
#dtparam=i2s=on
dtparam=spi=on

# Enable audio (loads snd_bcm2835)
dtparam=audio=on

# Additional overlays and parameters are documented
# /boot/firmware/overlays/README

# USER ADDED
#dtoverlay=imx219

# Automatically load overlays for detected cameras
camera_auto_detect=1

# Automatically load overlays for detected DSI displays
display_auto_detect=1

# Automatically load initramfs files, if found
auto_initramfs=1

# Enable DRM VC4 V3D driver
dtoverlay=vc4-kms-v3d
max_framebuffers=2

# Don't have the firmware create an initial video= setting in cmdline.txt.
# Use the kernel's default instead.
disable_fw_kms_setup=1

# Run in 64-bit mode
arm_64bit=1

# Disable compensation for displays with overscan
disable_overscan=1

# Run as fast as firmware / board allows
arm_boost=1

[cm4]
# Enable host mode on the 2711 built-in XHCI USB controller.
# This line should be removed if the legacy DWC2 controller is required
# (e.g. for USB device mode) or if USB support is not required.
otg_mode=1

[cm5]
dtoverlay=dwc2,dr_mode=host

[all]
enable_uart=1
dtoverlay=w1-gpio

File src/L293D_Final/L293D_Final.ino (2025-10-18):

#include <AFMotor.h>
#include <Servo.h>

#define FWD 1
#define BWD 2
#define BRK 3
#define REL 4

// USRT, USRE, USLT, USLE, USUT, USUE (ultrasonic right/left/up trig/echo)
#define USRT A0
#define USRE A1
#define USLT A2
#define USLE A3
#define USUT A4
#define USUE A5
#define US_BUFSIZE 30

bool _ZEROCHECK = false;

AF_DCMotor motor(3);
Servo svo;

// (set) motor speed
void mspd(int dir, int spd=255) {
  motor.setSpeed(spd);
  //if (dir != 0) motor.run(dir%4 + 1);
  motor.run(dir);
}

void steer(int dir) {
  svo.write(map(dir, 100, -100, 0, 180));
}

void shiftArray(float* arr) {
  for (int i = 0; i < US_BUFSIZE-1; ++i) {
    arr[i] = arr[i + 1];
  }
}


void setup() {
  Serial.begin(38400);
  Serial.print("-start-");
  svo.attach(9);
  motor.setSpeed(200);
  motor.run(RELEASE);

  pinMode(A0, OUTPUT);
//  pinMode(A1, INPUT);
  pinMode(A2, OUTPUT);
//  pinMode(A3, INPUT);
  pinMode(A4, OUTPUT);
//  pinMode(A5, INPUT);

  if (_ZEROCHECK) {
    svo.write(90);
    while(1);
  }
}

bool dir = true;

// debug led
void dl(bool o) {
  digitalWrite(13, o);
}

float buf_dl[30];
float buf_dr[30];
float buf_du[30];

// buffer average
float bufavg(float* arr) {
  int length = US_BUFSIZE;
  
  if (length == 0) { // handle edge case where array is empty
    return 0.0f; // or some other default value that makes sense
  }

  float sum = 0.0f;
  for (int i = 0; i < length; ++i) {
    sum += arr[i];
  }

  return sum / length;
}

float measureDist(int sensor) {
  
  //              T  E
  int uPins[2] = {0, 0};
  
  if (sensor < 0) {
    uPins[0] = USLT;
    uPins[1] = USLE;
  }
  if (sensor == 0) {
    uPins[0] = USUT;
    uPins[1] = USUE;
  }
  if (sensor > 0) {
    uPins[0] = USRT;
    uPins[1] = USRE;
  }
  
  // send pulse
  digitalWrite(uPins[0], LOW);
  delayMicroseconds(10);
  digitalWrite(uPins[0], HIGH);
  delayMicroseconds(2);
  digitalWrite(uPins[0], LOW);

  // Start timing after the HIGH pulse
  long duration = pulseIn(uPins[1], HIGH, 50000UL);

  if (duration == -1) {
    // Timeout occurred, return -1.0f
    return -1.0f;
  }
  else {
    // Calculate distance using the formula: distance = speed * time / 2
    float distance = (duration * 0.034 / 2);

    if (sensor < 0) {
      shiftArray(buf_dl);
      buf_dl[US_BUFSIZE - 1] = distance;
      distance = bufavg(buf_dl);
    }
    if (sensor == 0) {
      shiftArray(buf_du);
      buf_du[US_BUFSIZE - 1] = distance;
      distance = bufavg(buf_du);
    }
    if (sensor > 0) {
      shiftArray(buf_dr);
      buf_dr[US_BUFSIZE - 1] = distance;
      distance = bufavg(buf_dr);
    }

    return distance;
  }
}

void loop() {
  
//  while(0) {
//    Serial.println(measureDist(1));
////    digitalWrite(USLT, LOW);
////    delayMicroseconds(10);
////    digitalWrite(USLT, HIGH);
////    delayMicroseconds(2);
////    digitalWrite(USLT, LOW);
////  
////    // Start timing after the HIGH pulse
////    long duration = pulseIn(USLE, HIGH, 50000UL);
////    Serial.println(duration);
////  }

  // > ??
  // < 90

  Serial.println("began program");

  for (int i = 0; i < 30; i++) {
    measureDist(0);
  }
  
  while (1)//for (int lap = 0; lap < 3; lap++) {
    while (1) //for (int i = 0; i < 4; i++) {
      steer(-10);
      mspd(FWD, 200);

//      if (lap == 0 and i == 0) delay(600);

      float distF = measureDist(0);
      float distR = measureDist(1);
//      float distL = measureDist(-1);
      while(1) {
        distR = measureDist(1);
        distF = measureDist(0);
        Serial.println("gotten: " + String(distF));
        if (distF < 80) { // is front wall close enough?
          distR = measureDist(1);
          if ((distR) > 90) { // is right wall in sight?
            dir = true; // if so, direction should be set to right
          }
          else {
            dir = false; // if not, direction should be set to left
          }
          break;
        }
      }

      Serial.println("rt dist at fwd" + String(distR));
      // brake + reverse
      mspd(BWD, 170); // previously (150 then 170 then 200);
      delay(700); // previously (2200 (with 170 speed))
      
//      int fwdDelay = 1000;
//      if (i == 1) fwdDelay = 700;
//      if (i == 1 and lap == 1) fwdDelay = 1200;
//      delay(fwdDelay);
    
      steer(dir ? 50 : -80); // previously 50
      mspd(FWD, 200); // previously (150 then 170);
//      delay(dir ? 2000 : 2000); // previously (2200 (with 170 speed))
      for (int i = 0; i < 30; i++) {
        delay(dir ? (1200/30) : (1600/30));
        buf_du[i] = 110.0;
      }
  
  steer(0);
  mspd(FWD, 255); delay(750);
  
  mspd(FWD, 0);
  while(1); // halt code
}

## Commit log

2025-05-19 axle sketch
    [axle sketch.blend]
2025-05-21 basic hsv script on fake map
    [fake map test.blend]
2025-05-21 directory revamp to match WRO template
    [axle sketch.blend, fake map test.blend]
2025-05-22 minor change to the fake map test
    [fake map test.blend]
2025-06-03 added models
    [DetalK Bot.stl, camera module mount.stl]
2025-06-05 backed up current image of pi to start over
    [config.txt]
2025-06-21 slight changes
    [fake map test.blend]
2025-08-08 slightly changed virtual testing map + added ESC calibration tools
    [fake map test.blend]
2025-08-13 added more arduino tests for robot hardware
2025-08-29 added models and docs
    [BatteryColumn.stl, BatteryMount.stl, BoM.xlsx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]
2025-08-29 updated models
    [BatteryColumn.stl, BatteryMount.stl, BoM.xlsx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]
2025-08-29 Switch files
2025-08-30 added a few more arduino sketches
2025-10-18 Matlab motor analysis files
2025-11-08 New 3d model files
    [Base10172025.stl, Car BAse v1.stl, FrontAssembly10172025.stl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]
2025-11-08 xrp board pic
2025-11-09 Pi Camera images
2025-11-09 Lidar images
2025-11-09 IMU pics
2025-11-09 Ultrasonic pics
2025-11-10 uploaded some necessary schematics
2025-11-15 added existing models to repo
    [Base10172025.stl, BatteryColumn.stl, BatteryMount.stl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]
2025-11-18 Matlab files for torque calculation
2025-11-21 old image of XRP board
2025-11-21 added minor WPF based test for lidar experiment
2025-11-26 Wheels img
